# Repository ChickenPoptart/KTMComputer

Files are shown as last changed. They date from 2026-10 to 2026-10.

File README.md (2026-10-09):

# KTM Computer

A DIY dashboard and data logger for a **2020 KTM 690 Enduro R**, which has
no instrument cluster. An ESP32 "Cheap Yellow Display" reads the bike's
factory CAN bus (read-only) and a GPS module, shows a live dash on a 2.8"
touchscreen, keeps trip stats and charts, and logs everything to a MicroSD
card.

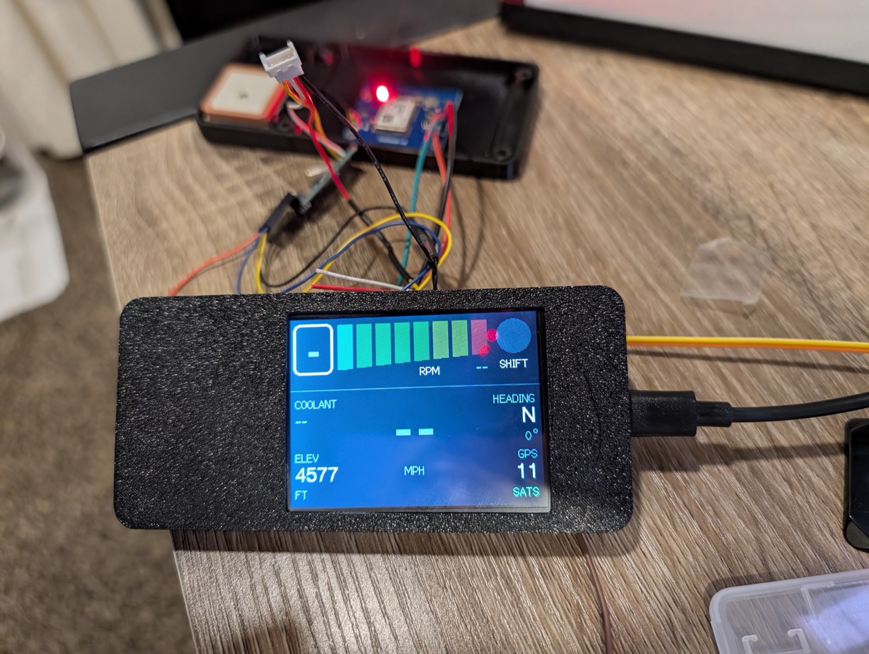
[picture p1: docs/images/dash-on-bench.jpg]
The dash on the bench: tach bar, gear, coolant, heading, elevation and GPS satellites, in a 3D-printed case with the GPS and wiring behind it


```mermaid
flowchart LR
    subgraph Bike
        ECU[ECU] --- BUS((CAN bus<br/>500 kbps))
        ABS[ABS unit] --- BUS
        BUS --- DIAG[6-pin diagnostic<br/>connector]
        DIAG --- DONGLE[Offroad ABS<br/>dongle]
        BAT[Battery]
    end
    DONGLE -- "CAN-H / CAN-L" --> XCVR[SN65HVD230<br/>CAN transceiver]
    DONGLE -- "switched 12 V" --> FUSE[1–2 A fuse] --> BUCK[12 V → 5 V<br/>converter]
    XCVR -- "CAN RX/TX (3.3 V)" --> CYD[ESP32-2432S028R<br/>'CYD' touchscreen]
    BUCK -- "5 V" --> CYD
    GPS[u-blox NEO-M8N<br/>GPS] -- "NMEA, 9600 baud" --> CYD
    CYD --> SD[(MicroSD<br/>ride logs)]
```

## What it does

- **Dashboard:** RPM with a colour-zoned tach bar and shift light, gear,
  speed (from the wheel sensor), coolant temperature, GPS heading,
  elevation, satellites, and the local time from GPS.
- **Trip and history pages:** distance, ride and moving time, maximums,
  climb and descent; charts of elevation, speed (wheel vs GPS) and coolant;
  time in each RPM zone. Every ride is saved, and `<` `>` buttons step
  through past rides.
- **CAN sniffer pages:** every CAN ID on the bus with its rate and live
  bytes, for reverse-engineering more signals.
- **Logging:** every CAN frame and GPS sentence to the SD card, one file per
  key-on, oldest deleted automatically when the card fills.
- **Read-only:** the CAN controller runs in listen-only mode. See the
  [wiring guide](docs/wiring.md#make-the-tap-truly-read-only) for the
  hardware change that guarantees it.

## Compatibility

| Bike | Years | Status |
|---|---|---|
| **KTM 690 Enduro R** | 2020 | **Built and tested** |
| KTM 690 Enduro R / SMC R | 2019+ | Same platform and electronics; should work |
| Husqvarna 701 Enduro / Supermoto | 2019+ era | Same platform and Bosch cornering ABS; should work, untested |
| GasGas ES 700 / SM 700 | 2022+ | Built on the same 690 platform; should work, untested |
| KTM 690 Enduro / SMC, older generation | pre-2019 | Different electronics (no IMU or cornering ABS); CAN signals probably differ, untested |

"Should work" means the hardware and logging will work and the
[CAN decoding](docs/can-signals.md) very likely matches; any differences
show up on the CAN sniffer pages and are a small code change.

**Diagnostic connector.** The tap is the 6-pin diagnostic connector under
the seat, near the battery's negative terminal:

- **2019–2020 (pre-Euro 5):** white connector (the tested bike).
- **2021+ (Euro 5):** most markets moved to a red connector with a
  different pin layout for the CAN wires. North American bikes may have kept
  the white one, so check the bike rather than going by year.

Either works: the [wiring guide](docs/wiring.md#finding-the-wires-with-a-meter)
finds the CAN pair, ground and switched 12 V with a meter, so wire colours
and pin positions don't need to match the tested bike.

**The offroad ABS dongle isn't required.** The tested bike splices into the
dongle's wires because one was fitted. Without one, splice into the bike
side of the diagnostic connector, or build a plug-in harness with the
mating 6-pin connector (Sumitomo MT 090 series) so nothing on the bike gets
cut.

## Screenshots

From a ride on the bike.

| | |
|---|---|
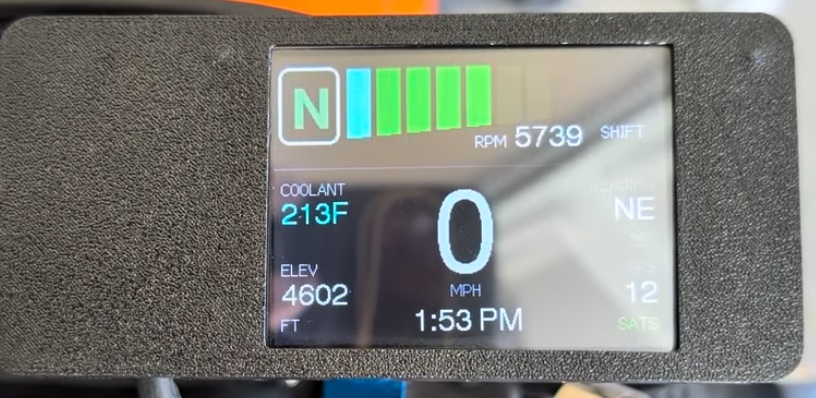
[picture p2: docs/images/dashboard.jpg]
Dashboard: neutral, 5,739 rpm on the green tach bar, coolant 213 °F, 0 mph, heading NE, elevation 4,602 ft, 12 satellites, 1:53 PM
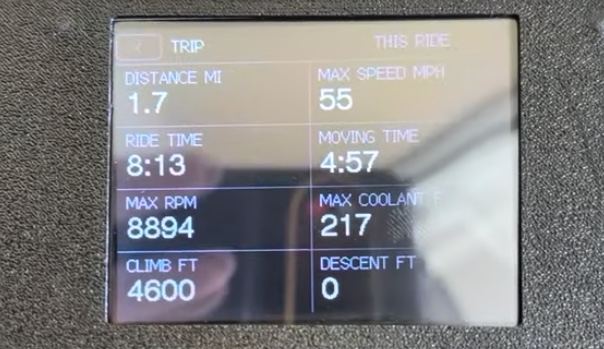
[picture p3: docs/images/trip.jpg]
Trip page: 1.7 mi, max 55 mph, ride time 8:13, moving time 4:57, max 8,894 rpm, max coolant 217 °F
|  |  |
| **Dashboard** | **Trip** |
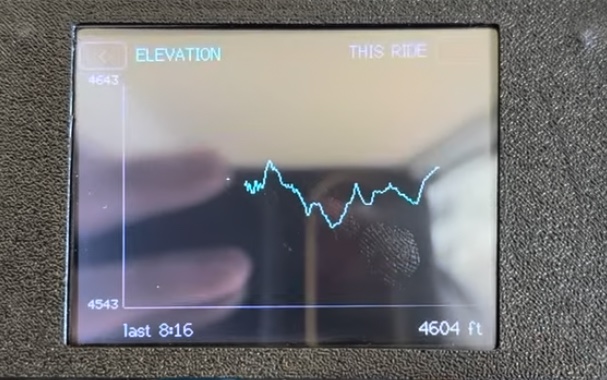
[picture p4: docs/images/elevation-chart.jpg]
Elevation chart over the ride, 4,543 to 4,643 ft
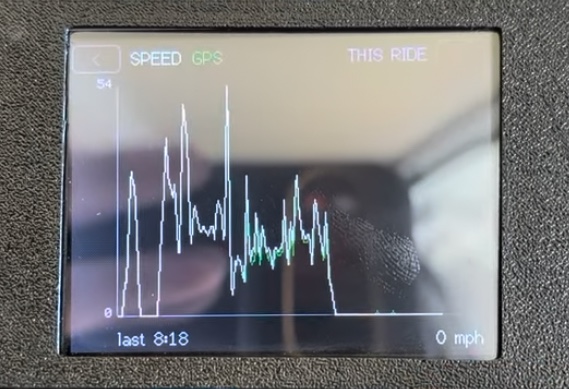
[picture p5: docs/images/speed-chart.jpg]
Speed chart: wheel speed with GPS speed overlaid, up to 54 mph
|  |  |
| **Elevation** | **Speed** (wheel, with GPS in green) |
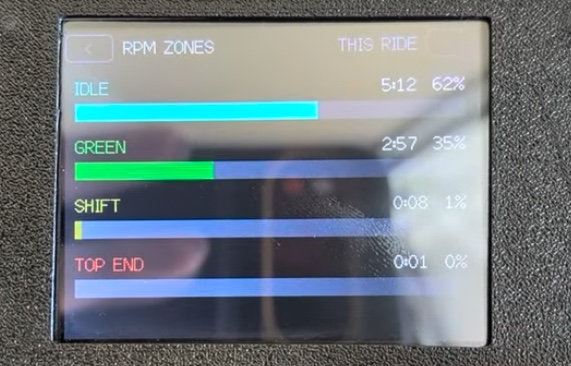
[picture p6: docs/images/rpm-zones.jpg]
RPM zones: idle 62%, green 35%, shift 1%, top end 0%
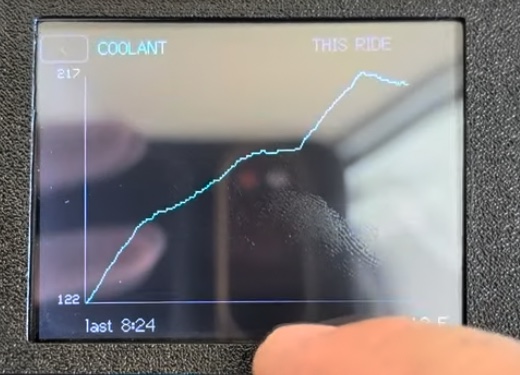
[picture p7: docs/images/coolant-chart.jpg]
Coolant chart warming from 122 °F to 217 °F
|  |  |
| **RPM zones** | **Coolant** |
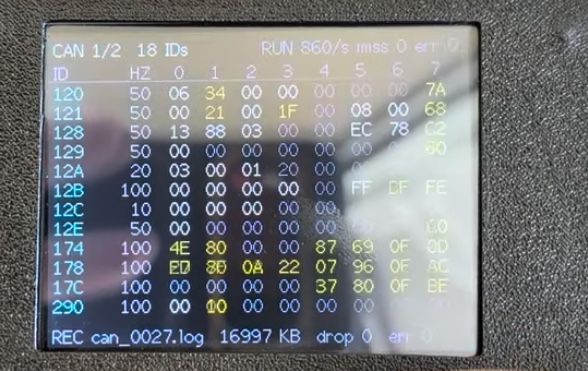
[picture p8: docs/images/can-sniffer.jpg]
CAN sniffer page: 18 IDs at 860 frames/s with live bytes, recording to can_0027.log, no drops
|  | |
| **CAN sniffer** | |

## Documentation

| Doc | What's in it |
|---|---|
| [Parts list](docs/parts-list.md) | Everything used in the build |
| [Wiring](docs/wiring.md) | Every wire: bike, power, transceiver, GPS, with pin tables |
| [Build guide](docs/build-guide.md) | Step by step: tools, flashing, wiring, testing on the bike |
| [Using the dash](docs/using-the-dash.md) | Pages, taps, long presses, ride history |
| [CAN signals](docs/can-signals.md) | What each CAN ID and byte means on this bike |
| [Log format](docs/log-format.md) | What's in the SD card logs and how to read them |
| [Firmware](docs/firmware.md) | Code layout, tests, settings you might change |
| [Troubleshooting](docs/troubleshooting.md) | Problems hit during the build and how they were found |
| [Roadmap](docs/roadmap.md) | What's done and what's next |
| [Case](hardware/case/README.md) | 3D-printable case (STL) |
| [Captures](captures/README.md) | Raw CAN logs from the bike |

## Quick start (firmware)

1. Install [VS Code](https://code.visualstudio.com/) and the
   [PlatformIO](https://platformio.org/install/ide?install=vscode) extension.
2. Clone this repo and open the folder in VS Code.
3. Plug the CYD into the computer by USB and press **Upload** in the
   PlatformIO toolbar (or run `pio run -e esp32dev -t upload`).
4. Run the unit tests on the computer with `pio test -e native`.

See the [build guide](docs/build-guide.md) for the hardware.

## Credits

The starting point for the CAN decoding is
[blalor/ktm-can](https://github.com/blalor/ktm-can), also from a 2020 690
Enduro R, built on Dan Plastina's SuperDuke 1290 work on ADVrider. This
project confirmed and extended it from its own ride logs.

## License

**Free for personal and other noncommercial use.**

- **Code** (`src/`, `lib/`, `test/`, `platformio.ini`):
  [PolyForm Noncommercial 1.0.0](LICENSE)
- **Docs, images, 3D files and captures:**
  [CC BY-NC-SA 4.0](LICENSE-docs.md): credit this project and share
  adapted versions under the same terms

Build one for your own bike, modify it, share it with friends and
clubs: all fine.

### Commercial use

Selling kits or finished units, including this in a product, or charging to
install it needs a commercial license. To ask, open an issue using the
[**Commercial license request**](https://github.com/ChickenPoptart/KTMComputer/issues/new?template=commercial-license.md)
template.

### Earlier versions

Versions published before 9 October 2026 (up to commit `f2c9ddf`) were
released under the MIT License, and anyone who got a copy of those versions
keeps the MIT terms for them.

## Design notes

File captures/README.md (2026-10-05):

# CAN captures

Raw logs from the bike, in the [log format](../docs/log-format.md)
(candump lines, plus `mark` lines for markers). All are from firmware that
lost 25–50% of frames ([why](../docs/troubleshooting.md#lost-can-frames-fixed)),
so rolling counters skip; slower signals are still usable.

GPS lines are removed from anything published here, since they show where
the bike was.

| File | Length | What happened |
|---|---|---|
| `2026-09-28_first_start_can_0005.log` | 40 s | First key-on: ECU wakes at ~16 s, cold start at ~25 s, idle ~1,700 rpm, engine off at 39 s |
| `2026-10-01_can_0007.log` | 35 s | Key-on |
| `2026-10-01_can_0008.log` | 89 s | Key-on with 5 markers (first attempt at the test plan) |
| `2026-10-01_can_0009.log` | 14 s | Key-on |
| `2026-10-01_can_0010.log` | 6.5 min | **Full test ride with 13 markers** (below) |

## Markers in `2026-10-01_can_0010.log`

| Mark | Action | Found |
|---|---|---|
| 1 | Front brake, squeezed 3× | `290` D0–D1 |
| 2 | Rear brake, 3× | nothing distinctive |
| 3 | Clutch in/out 3× | `129` D0 bit 3 |
| 4 | Kickstand up, then down | `540` D4 bit 0 |
| 5 | TC button | `450` D2 bit 0 |
| 6 | Throttle map changed and back | `12A` D1 bit 6, `120` D4 bit 0, `450` D4 |
| 7 | Leaning left / right | `178`, `17C` swing |
| 8 | Throttle sweeps (engine started in this window) | `120` D2, `121` D1/D3 |
| 9 | Roll-on to ~5,000 rpm | |
| 10 | Throttle blips | |
| 11 | Steady ~20–25 mph (1st gear) | `12B` wheel speeds ~615 raw |
| 12 | Steady ~38–42 mph (2nd gear) | `12B` ~1,113 raw |
| 13 | Normal riding | |

## Reading them

```sh
# CAN frames only
grep ' can0 ' 2026-10-01_can_0010.log

# One ID
grep ' can0 120#' 2026-10-01_can_0010.log
```

Tools that read candump logs (python-can, SavvyCAN, cantools) can open the
files once the `mark` lines are filtered out.

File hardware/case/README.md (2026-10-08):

# Case for the 2.8" CYD dash

`cyd-case.stl` is the 3D-printed case for the current build (ESP32-2432S028R
"Cheap Yellow Display"). All parts are laid out on one plate, 207 × 167 mm,
so it prints in one go on a 220 mm bed or larger.

| Part | Size (mm) | What it is |
|---|---|---|
| Dash front | 119 × 55 × 13 | Holds the CYD, with the screen opening |
| Dash back | 119 × 55 × 8 | Back cover |
| Electronics box | 58 × 123 × 17 | Houses the GPS and wiring |
| Posts (×4) | 6.5 × 6.5 × 20 | Standoffs |

The file also contains two zero-thickness slivers left over from export;
slicers ignore them.

## Printing

- **PETG or ASA**, not PLA: a black case on handlebars gets hot enough in
  the sun to warp PLA.
- The GPS antenna works through the plastic (1.5 mm PETG tested fine), so
  keep the GPS box's lid plastic, with no metal above the antenna.
- Leave the SD card slot and USB-C reachable for pulling logs and flashing.

See the [build guide](../../docs/build-guide.md#8-mounting) for mounting.

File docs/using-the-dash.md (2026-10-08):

# Using the dash

## Touch

| Gesture | Does |
|---|---|
| **Tap** | Next page (shows ~⅓ s after lifting, to tell it from a double tap) |
| **Double tap** | Back to the dashboard, from any page, and back to this ride |
| **Hold ~1 s** on the dashboard or CAN pages | Drops a numbered **marker** into the log (yellow `MARK n` box) |
| **Hold ~1 s** on a trip or chart page | Shows **TAP TO CLEAR**: tap within 3 s to clear that page's data for this ride, or wait to cancel |
| **`<` / `>`** (top corners of the trip and chart pages) | Step to older / newer saved rides |

## Pages

Tap to cycle in this order:

1. **Dashboard:** tach bar, RPM, shift light, gear, speed, coolant, GPS
   heading, elevation, satellites, time.

   Dashboard

2. **Trip:** distance, max speed, ride time, moving time, max RPM, max
   coolant, climb, descent.

   Trip page

3. **Elevation** chart (GPS).

   Elevation chart

4. **Speed** chart: wheel speed (white) with GPS speed (green).

   Speed chart

5. **RPM zones:** time and share in idle, green, shift and top end.

   RPM zones

6. **Coolant** chart.

   Coolant chart

7. **CAN pages:** every CAN ID with its rate and bytes (yellow = changed
   in the last second, white = has changed, grey = never changed), plus bus
   state and SD recording status.

   CAN sniffer page

## Dashboard

| Item | Source | Notes |
|---|---|---|
| Tach bar | RPM (`0x120`) | Cyan from 1,000 (idle), green 3,000–5,700, yellow 6,500–7,300, red at 8,200, where the bar flashes and the shift light comes on. Thresholds are `TACH_SEGMENT_RPM` in `lib/dash_logic/src/dash_logic.h` |
| Gear | `0x129` | `N` in green; `-` with no data |
| MPH | Front wheel speed (`0x12B`) | Instant (100 updates/s). Scale ~27.4 counts per mph, about ±5% until calibrated against GPS |
| Coolant | `0x540` | °F |
| Heading | GPS course | Only updates above 3 mph; holds the last heading when stopped |
| Elevation | GPS altitude | ±30–60 ft typical |
| GPS / SATS | GPS | `NO FIX` until it has a position |
| Time | GPS | Mountain time with daylight saving. `--:--` until the GPS sets the clock. Shows **CAN FAULT** in red instead if the CAN wiring looks broken |

Anything that stops arriving for more than a second turns to `--`.

## Trip, charts and ride history

- Everything is collected all the time, whatever page is showing, starting
  fresh at each key-on.
- Charts take a point every 2 seconds. Each holds 280 points; when full,
  neighbouring points are averaged in pairs, so the chart always shows the
  **whole ride**, at less detail the longer it gets. Maximums on the Trip
  page are tracked separately at full speed, so short spikes are never lost.
- Climb/descent ignores GPS jitter smaller than 30 ft.
- **A ride** is one key-on with at least a minute of engine running. It's
  saved to the SD card every 30 seconds (`/rides/ride_NNNN.bin`), so turning
  the key off loses at most 30 s. Bench power-ups aren't saved.
- On a past ride the header shows its number and date, e.g.
  `#17 Sat Oct 4`. Past rides can't be cleared.

## Markers

Hold on the dashboard to mark a moment ("I squeezed the front brake now").
Markers go into the log as `mark` lines, so the bytes that changed at that
moment are easy to find later. The count restarts at 1 each key-on.

## The SD card

- One `can_NNNN.log` per key-on, plus `/rides/` for ride history.
- Copy logs you want to keep. When the card is under 10% free at boot, the
  oldest logs (and their ride history) are deleted.
- After the GPS has a fix, files get real dates on the computer.

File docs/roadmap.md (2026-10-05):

# Roadmap

## Done

- Read-only CAN sniffer with SD logging (every frame, candump format)
- Live dashboard: RPM and colour-zoned tach, shift light, gear, wheel
  speed, coolant
- CAN signal decoding for RPM, gear, coolant, wheel speed, brake, clutch,
  kickstand, TC and map buttons ([CAN signals](can-signals.md))
- Event markers (hold on the dashboard)
- GPS (NEO-M8N): fix, satellites, heading, elevation, local time with
  daylight saving; every sentence logged
- Trip page, elevation / speed / coolant charts, RPM zone breakdown
- Ride history: every ride saved, `<` `>` to browse; double tap to the
  dashboard
- Automatic log rotation when the card fills
- CAN error guard and loop profiling notes
- Running on the bike from VIN power, with the bus short repaired (2026-10-05)

## Next

- **Calibrate wheel speed against GPS speed** from a ride log, replacing
  the ±5% estimate
- **Read-only hardware change:** tie the transceiver's CTX to 3.3 V
  ([why](wiring.md#make-the-tap-truly-read-only))
- **GPX export** script for the computer: ride tracks coloured by speed or RPM
- More signals: rear brake, `300` (check with the dongle unplugged),
  lean angle, and the unknown IDs
- 3D-printed case and handlebar mount

## Maybe later

- GPS at 10 Hz (needs the GPS RX wire, from a freed RGB LED pin)
- BMP280 barometer for smoother elevation
- Magnetometer for heading at a standstill
- Live displays for the newly found signals (map, TC, kickstand warning)

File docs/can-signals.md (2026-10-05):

# CAN signals — 2020 KTM 690 Enduro R

What each CAN message on this bike carries, as far as it's been worked out.
The bus runs at **500 kbps** with standard 11-bit IDs. Bytes are D0..D7;
multi-byte values are big-endian (high byte first).

## What the dash uses

| Shown as | ID | Bytes | Conversion |
|---|---|---|---|
| RPM | `0x120` | D0–D1 | value = RPM |
| Gear | `0x129` | D0 high nibble | 0 = neutral, 1–6 |
| Coolant | `0x540` | D6–D7 | value ÷ 10 = °C (dash shows °F) |
| Speed | `0x12B` | D0–D1 (front wheel) | value ÷ 27.4 = mph |

Decoding lives in `lib/dash_logic/src/ktm_decode.cpp`, with tests in
`test/test_ktm_decode`. A value that stops arriving for over a second shows
as `--`.

## All IDs seen
"Source" is which module starts sending first after key-on: the ECU starts
3–70 s after key-on, the others immediately (most likely the ABS unit).

Starting point: [blalor/ktm-can](https://github.com/blalor/ktm-can) (also a
2020 690 Enduro R). Marked **confirmed** where our own logs show it; ride
evidence is [`captures/2026-10-01_can_0010.log`](../captures/README.md) (13 markers, see below).

| ID | Period | Source | Contents | Status |
|---|---|---|---|---|
| `120` | 20 ms | ECU | D0–D1 engine rpm. D2 commanded throttle 0–255. D3 bit 4 kill switch (1 = run). D4 bit 0 throttle map in use. D7 high bits rolling counter | rpm, map **confirmed**; on dash |
| `121` | 20 ms | ECU | D1 and D3 rise together with the throttle grip (likely the two redundant ride-by-wire grip sensors). D7 rolling counter | candidate |
| `128` | 20 ms | key-on | `7FFF…` until the ECU wakes, then fixed values. D2 toggles 02/03 with the engine running | unknown |
| `129` | 20 ms | ECU | D0 high nibble gear (0 = N, 1–6); D0 bit 3 clutch pulled. D7 rolling counter | gear, clutch **confirmed**; gear on dash |
| `12A` | 50 ms | key-on | D1 bit 6 requested throttle map. D0 throttle open/closed bits | map **confirmed** |
| `12B` | 10 ms | key-on | D0–D1 front wheel speed, D2–D3 rear wheel speed (front and rear agree within ~3%). D5–D7 tilt/lean (12-bit pairs) | speed **confirmed**; front wheel on dash (~27.4 counts/mph); lean unverified |
| `12C` | 1 s | key-on | All zero when stopped; two 12-bit values that follow wheel speed (slower, different scale) | candidate |
| `12E` | ~100 ms | key-on | D0 status flag (00/40). D7 counter | unknown |
| `174` `178` `17C` | 10 ms | key-on | Lean/motion sensor: each has two 16-bit values centred near 0x8000 (one offset by gravity), a 4-bit counter in D6 low nibble, and a checksum in D7. `178` D0–D1 and `17C` D4–D5 swing most when leaning the bike | strong candidate |
| `290` | 10 ms | key-on | D0–D1 front brake pressure (rises only with the front lever) | **confirmed** |
| `300` | 200 ms | key-on | Always `0F…` | possibly the offroad ABS dongle; check with it unplugged |
| `450` | 50 ms | key-on | D2 bit 0 traction control button. D4 `09`/`00` with the map button | TC, map **confirmed** |
| `540` | 100 ms | ECU | D1–D2 rpm (slower copy). D3 low nibble gear. D4 bit 0 kickstand up; bit 4 key on, engine not running. D6–D7 coolant, tenths of °C | kickstand, coolant **confirmed**; coolant on dash |
| `541` | 200 ms | ECU | Always `02 80` | ECU status, unknown |
| `550` | 200 ms | key-on | D0 status flag (00/10). D7 counter | unknown |
| `5A0` | 1 s | key-on | D1/D2 change once after the ECU wakes | unknown |

Not found yet: **rear brake** (the pedal changed nothing distinctive).

## Wheel speed scale (`12B`)

Steady stretches from the 2026-10-01 ride, read against the bike's
speedometer:

| Speedometer | Steady stretch | Rear raw | Front raw | Gear |
|---|---|---|---|---|
| 20–25 mph | 219–232 s | ~615 | ~602 | 1 |
| 38–42 mph | 265–270 s | ~1,113 | ~1,095 | 2 |

The only scale that fits both runs is 26.5–29.3 rear counts per mph; the
midpoint ≈ 28 gives 22 and 40 mph. The front wheel reads ~2% lower, so the
dash uses 27.4 front counts per mph (`FRONT_COUNTS_PER_10_MPH` in
`lib/dash_logic/src/ktm_decode.cpp`). Expect about ±5%; a GPS track would
pin it down. The raw value is not a round km/h unit (0.05 and 0.0625 km/h
per count both fall outside the speedometer ranges). Logs now include GPS
speed, which will give an exact calibration.

## Ride markers (`captures/2026-10-01_can_0010.log`)

1 front brake · 2 rear brake · 3 clutch · 4 kickstand · 5 TC button ·
6 throttle map · 7 lean left/right · 8 throttle sweep · 9 roll-on to 5,000 ·
10 blips · 11 steady 20 mph · 12 steady 40 mph · 13 normal ride

## Log quality

Firmware before 2026-10-01 echoed changed frames to Serial, which blocked
the loop about every 10 ms and lost 25–50% of frames (visible as skipped
rolling counters in `120`, `129`, `174`). Slow signals are still usable.

## Reading the bytes yourself

- A frame in the log looks like `(12.345678) can0 120#06A4101000000030`:
  ID `120`, data `06 A4 10 10 00 00 00 30`. D0–D1 = `06A4` = 1700 rpm.
- **Rolling counters** (a byte or nibble stepping by a fixed amount every
  frame) show up in many IDs. A skipped step means a frame was lost, which
  is how frame loss in early logs was measured.
- To find a new signal: hold the screen on the dashboard to drop a marker,
  do the action, and compare which bytes change after the marker but not
  in quiet stretches. That's how the brake, clutch, kickstand, TC and map
  bits above were found.

## Still to find

- Rear brake (the pedal changed nothing distinctive)
- What `300` is: log one key-on with the offroad dongle unplugged
- `121`, `128`, `12C`, `12E`, `541`, `550`, `5A0`: unknown or only partly known
- Lean angle scaling (`12B` D5–D7, and the motion sensor IDs)

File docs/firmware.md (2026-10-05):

# Firmware

PlatformIO project, Arduino framework on the ESP32. Two environments:

| Environment | Command | What |
|---|---|---|
| `esp32dev` | `pio run -e esp32dev -t upload` | Builds and flashes the CYD |
| `native` | `pio test -e native` | Runs the unit tests on the computer |

## Layout

Logic that doesn't touch hardware lives in `lib/dash_logic/` and has unit
tests in `test/`. Code that talks to the display, CAN controller, GPS, touch
panel or SD card lives in `src/`.

### `lib/dash_logic/src/` (tested on the computer)

| File | Does |
|---|---|
| `ktm_decode` | Turns CAN frames into RPM, gear, coolant, speed, with staleness |
| `can_tracker` | Per-ID table for the CAN pages (rates, changed bytes) |
| `can_guard.h` | Decides when a CAN error flood means CAN should pause |
| `candump_format` | Log line formats: CAN frames, markers, GPS sentences |
| `dash_logic` | Tach segments and colour zones, gear labels, compass points, durations |
| `gps_view.h` | GPS fix, heading hold below 3 mph, elevation |
| `ride_clock` | GPS date/time to epoch, Mountain time with daylight saving |
| `trip_stats.h` | Distance, times, maximums, climb/descent, time per RPM zone |
| `chart_series.h` | Chart storage that merges pairs so a whole ride fits |
| `ride_history.h` | Ride file names, which rides to save, `<` `>` browsing |
| `log_rotation` | Log file numbering and deleting the oldest when the card fills |
| `press_detector.h`, `tap_sequencer.h` | Tap / long press / double tap from the touch panel |
| `reset_prompt.h` | The two-step "TAP TO CLEAR" |
| `touch_map.h` | Touch calibration: raw panel readings to screen pixels |
| `loop_profiler.h` | Where the main loop's time goes (diagnostic notes) |

### `src/` (hardware)

| File | Does |
|---|---|
| `main.cpp` | Setup, the main loop, pages, touch handling, ride saving |
| `can_bus` | ESP32 TWAI controller, listen-only, 500 kbps, plus the error guard |
| `gps` | NEO-M8N on UART2 (IO35), TinyGPSPlus parser, logs every sentence |
| `sd_log` | SD card, background writer task on core 0, log rotation, notes |
| `ride_store` | Saves and loads `/rides/ride_NNNN.bin` |
| `touch` | Bit-banged XPT2046 touch controller |
| `dash_ui`, `trip_page`, `chart_page`, `zones_page`, `can_page`, `history_header` | Screens |
| `telemetry.h` | What the dashboard shows |

## Settings you might change

| Setting | File | Default |
|---|---|---|
| Tach colour zones | `TACH_SEGMENT_RPM` in `dash_logic.h` | 1000 / 3000 / 3900 / 4800 / 5700 / 6500 / 7300 / 8200 |
| Shift light | `SHIFT_RPM` in `dash_logic.h` | 8,200 |
| Speed scale | `FRONT_COUNTS_PER_10_MPH` in `ktm_decode.cpp` | 274 (27.4 counts per mph) |
| Time zone | `MOUNTAIN_TZ` in `ride_clock.h` | US Mountain with DST |
| Screen rotation | `SCREEN_ROTATION` in `main.cpp` | 1 (redo touch calibration if changed) |
| Free space kept on the card | `MIN_FREE_PERCENT` in `log_rotation.h` | 10% |
| Minimum engine time for a saved ride | `RIDE_MIN_SECONDS` in `ride_history.h` | 60 s |
| Double-tap window | `DOUBLE_TAP_MS` in `tap_sequencer.h` | 350 ms |

Changing anything in `RideRecord` (`src/ride_store.h`) or what it contains
changes the saved-ride file layout: bump `RIDE_VERSION` in
`ride_store.cpp` so older files are skipped instead of misread.

## How the main loop runs

Each pass: drain up to 64 CAN frames, read the GPS, update trip stats
(every 100 ms) and charts (every 2 s), save the ride (every 30 s), handle
touch, then redraw the current page at its own rate (dashboard every
40 ms). Nothing in the loop waits on hardware: SD writes go through a queue
to a task on the other core, and serial carries only occasional status
lines.

## Serial output (USB, 115200 baud)

Status only: boot messages, a GPS line every 5 seconds
(`# GPS chars=… sats=… fix=… time=…`), and the same `note` lines that go
into the log.

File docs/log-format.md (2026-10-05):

# SD card ride logs

One file per power-up: `can_NNNN.log`. Numbers only go up (one past the
highest on the card), so the lowest number is the oldest log.

Every line starts with a timestamp in seconds since boot, then a channel:

| Channel | Example | What |
|---|---|---|
| `can0` | `(12.345678) can0 120#05DC101000000030` | Every CAN frame from the bike, candump format |
| `mark` | `(31.676005) mark 000#0001` | Long-press marker number (hex), restarts at 1 each boot |
| `nmea` | `(3.250000) nmea $GNRMC,…*47` | Every sentence from the NEO-M8N GPS, unchanged |
| `note` | `(10.000172) note loop passes=576448 slowest=21ms …` | Diagnostics in plain text (see below) |

`can0` and `mark` lines are valid candump syntax; tools that read candump
logs may need the `nmea` and `note` lines filtered out first
(`grep -v -e ' nmea ' -e ' note ' can_0012.log`). GPS tools that read NMEA can take the
sentences with `grep ' nmea ' can_0012.log | cut -d' ' -f3-`.

## Notes

| Note | When | Says |
|---|---|---|
| `boot reset_reason=… can=… sd=…` | At startup | Why the board last reset (1 = power-on), whether CAN and the SD card started |
| `loop passes=… slowest=…ms can=…ms gps=…ms …` | Every 10 s | How many main-loop passes ran and where the time went; ~600,000 passes per 10 s is normal. Also SD bytes written and lines dropped |
| `can frames=… errors=…` | Every 10 s | Running totals from the CAN controller; `FAULT` while an error flood is being handled |
| `CAN error flood …: CAN off for 10 s` / `CAN restarted` | On a fault | The [CAN error guard](troubleshooting.md#can-fault-on-the-dash) acting |

## Ride history files

`/rides/ride_NNNN.bin` holds the trip stats and charts for the ride logged
in `can_NNNN.log`, saved every 30 seconds. It's a raw memory image with a
small header (magic `KTMR`, version, size); files from a different firmware
version are skipped rather than misread.

## Space on the card

At boot, before recording starts, the firmware deletes the oldest logs
until at least 10% of the card is free (`MIN_FREE_PERCENT` in
`lib/dash_logic/src/log_rotation.h`). A log is roughly 50–80 MB per hour of
riding, so 10% of a 32 GB card is ~40 hours: one ride can't fill it, and
nothing is deleted mid-ride. Copy logs you want to keep off the card; old
ones disappear once it fills.

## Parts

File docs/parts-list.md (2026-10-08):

# Parts list

What this build uses. Exact brands mostly don't matter; the notes say what
does.

## Electronics

| Part | Qty | Notes |
|---|---|---|
| **ESP32-2432S028R** ("Cheap Yellow Display", CYD) | 1 | ESP32 with a 2.8" 320×240 ILI9341 screen, resistive touch, MicroSD slot. The firmware's pins and touch calibration are for this board |
| **SN65HVD230 CAN transceiver board** | 1 | 3.3 V CAN transceiver, chip marked "VP230". Leave its 120 Ω termination jumper **off** (the bike's bus is already terminated) |
| **u-blox NEO-M8N GPS breakout** with ceramic patch antenna | 1 | Breakout marked NEO-M8N-0-10. Pins: VCC, GND, TX, RX. Runs from the CYD's 3.3 V. No compass on this one |
| **12 V → 5 V converter** with USB-A output | 1 | Any automotive buck converter rated 1 A or more at 5 V. Use USB-A, not a USB-C PD charger |
| **Inline fuse holder + 1–2 A fuse** | 1 | On the converter's 12 V input |
| **MicroSD card**, FAT32 | 1 | 32 GB or smaller (larger cards ship as exFAT, which the board can't read). Holds hundreds of hours of logs |

## Wire and connectors

| Part | Notes |
|---|---|
| **Cat5e or Cat6 cable** | For the run from the bike tap to the transceiver. CAN-H and CAN-L go on **one twisted pair**; a spare conductor carries ground |
| **USB-A cable** (sacrificial) | Cut to make the 5 V lead from the converter to the CYD's VIN. Inside: +5 V (gray in the one used), ground (bare drain wire/shield), data wires unused |
| **JST 1.25 mm 4-pin pigtails** (also sold as MX1.25 / Molex PicoBlade-compatible) | Fit the CYD's CN1, P3 and power connectors. One cable usually comes with the CYD. Not the same as 2.0 mm JST-PH |
| **Heat-shrink tubing**, assorted | One piece per joint. See the [warning in troubleshooting](troubleshooting.md#a-melted-wire-shorted-the-bus) about heat |
| **Solder**, flux, thin hookup wire (28–30 AWG for fine joints) | |
| Zip ties | Strain relief at every joint |
| Quick disconnect (optional) | Any cheap latching connector between the bike pigtail and the dash, e.g. JST-SM 4-pin. Put the socket half on the bike side |

## Already on the bike

| Part | Notes |
|---|---|
| **Offroad ABS dongle** | Plugs into the 6-pin diagnostic connector under the seat. The dash taps the dongle's wires, so the dongle must stay plugged in |

## Tools

| Tool | Used for |
|---|---|
| Multimeter (a basic manual-range one is fine) | Finding the CAN pair, checking power, finding shorts |
| Soldering iron | All joints |
| Heat gun or lighter | Heat-shrink, carefully |
| Computer with VS Code + PlatformIO | Building and flashing the firmware |
| USB cable for the CYD | Flashing and serial monitor |

## Planned / optional

| Part | Why |
|---|---|
| 3D-printed case (PETG or ASA, not PLA): [`hardware/case`](../hardware/case/README.md) | PLA warps in the sun. The GPS works through 1.5 mm of PETG |
| Handlebar mount (e.g. RAM 1" ball with an AMPS plate) | Quick removal when it rains |
| BMP280 barometer | Smoother elevation than GPS alone |
| Magnetometer | Compass heading while stopped (hard to calibrate near the frame) |

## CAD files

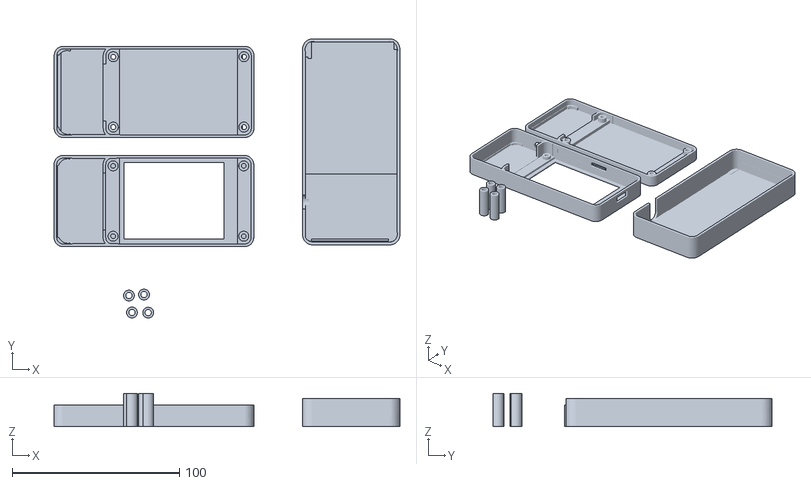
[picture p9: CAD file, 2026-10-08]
hardware/case/cyd-case.stl
206.6 x 166.7 x 20.0

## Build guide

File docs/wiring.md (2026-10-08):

# Wiring

Every wire in the build. Wire colours on the bike side are from this
bike's offroad ABS dongle (2020, white pre-Euro 5 diagnostic connector);
**confirm yours with a meter** before cutting anything (see
[Finding the wires](#finding-the-wires-with-a-meter)). Other model years
and connectors are covered under [Compatibility](../README.md#compatibility).

```mermaid
flowchart LR
    subgraph Dongle["Offroad ABS dongle wires (bike side)"]
        TAN[Tan<br/>switched 12 V]
        BRN[Brown<br/>ground]
        BB[Blue/black<br/>CAN-H]
        BW[Blue/white<br/>CAN-L]
    end
    TAN --> FUSE[1–2 A fuse] --> CIN[Converter 12 V +]
    BRN --> CGND[Converter 12 V −]
    BRN --> XGND[Transceiver GND]
    BB --> XH[Transceiver CANH]
    BW --> XL[Transceiver CANL]
    CIN -.-> CONV[12 V → 5 V converter]
    CONV -- "gray: +5 V" --> VIN[CYD VIN]
    CONV -- "drain wire: GND" --> CYDGND[CYD GND]
    subgraph CN1["CYD CN1"]
        R[Red 3V3]
        Y[Yellow IO27]
        BL[Blue IO22]
        BK[Black GND]
    end
    R --> X3[Transceiver 3V3]
    Y --> XR[Transceiver CRX]
    BL --> XT[Transceiver CTX]
    BK --> XGND
    R --> GV[GPS VCC]
    GT[GPS TX] --> P35[CYD P3 IO35]
    GG[GPS GND] --> P3G[CYD P3 GND]
```

## 1. Bike: the offroad ABS dongle

The dongle plugs into the bike's 6-pin diagnostic connector under the seat
(below the ECU). The dash splices into the **dongle's** wires, so the
dongle has to stay plugged in.

| Dongle wire | Signal | Goes to |
|---|---|---|
| **Tan** | Switched 12 V (live only with the key on) | Inline **1–2 A fuse**, then converter 12 V **+** |
| **Brown** | Ground | Converter 12 V **−**, and transceiver **GND** |
| **Blue/black** | **CAN-H** | Transceiver **CANH** |
| **Blue/white** | **CAN-L** | Transceiver **CANL** |

- Run CAN-H and CAN-L on **one twisted pair** of Cat5e/6, untwisted as little
  as possible at the ends. Use a spare conductor for ground.
- Keep the branch from the dongle to the transceiver short (a foot or two).
- Take both grounds (converter − and transceiver GND) from the **same**
  brown-wire splice point.
- **Tan never connects to the CYD, transceiver or GPS.** 12 V destroys them.

## 2. Power

```
Tan (12 V, switched) ──fuse──► converter ──5 V──► CYD VIN ──► CYD 3.3 V regulator ──► CN1 red (3V3)
                                                                                          ├──► transceiver 3V3
                                                                                          └──► GPS VCC
```

Power enters only at **VIN**. The CYD makes 3.3 V and supplies it on CN1's
red wire; the transceiver and the GPS run from that.

**Converter to CYD** (a cut USB-A cable, plugged into the converter):

| Cable wire | CYD power connector (labelled VIN / TX / RX / GND) |
|---|---|
| **Gray** (+5 V in the cable used; check yours) | **VIN** |
| **Bare drain wire** (+ shield) | **GND** |
| Green, white (data) | Not connected; insulate each |
| — | **TX, RX: not connected** (they're the USB serial lines) |

Find +5 V in your cable with the meter on DC volts: with the converter
powered, the pair that reads **+5.0 V** (red probe on +) is power.

- Never put 5 V on 3V3, the transceiver or the GPS.
- **Don't connect USB and VIN at the same time.** Unplug the bike side
  before plugging the CYD into a computer to flash it.

## 3. CYD CN1 → CAN transceiver

| CN1 pin | Wire | ESP32 | Transceiver |
|---|---|---|---|
| 1 | Red | 3V3 | **3V3** |
| 2 | Yellow | IO27 (CAN RX) | **CRX** |
| 3 | Blue | IO22 (CAN TX) | **CTX** (see below) |
| 4 | Black | GND | **GND** |

Termination: the bike's bus already has both 120 Ω terminators (measured
**60.2 Ω** across CAN-H/CAN-L, key off, dongle plugged in). Leave the
transceiver's 120 Ω jumper **off**.

### Make the tap truly read-only

The firmware runs the CAN controller in listen-only mode: it never sends
frames or acknowledgements. But on the ESP32, a listen-only controller can
still drive **error flags** onto the bus when it sees errors (chip errata;
the workaround isn't enabled in this framework build). To make it
physically impossible for the dash to transmit:

- Disconnect the blue IO22 wire from the transceiver's **CTX**.
- Connect **CTX to 3.3 V** (the red 3V3 line).

The transceiver then holds the bus "recessive" (silent) whatever the ESP32
does. No firmware change is needed.

## 4. GPS (u-blox NEO-M8N)

| GPS pin | CYD |
|---|---|
| **VCC** | 3.3 V: splice into CN1's **red** wire |
| **GND** | **P3 GND**, or CN1's black wire |
| **TX** | **P3 IO35** (UART2 receive; IO35 is input-only, which is all it needs) |
| **RX** | Not connected; insulate it |

- P3 also carries **IO22** (the same CAN TX line as CN1) and on many boards
  **IO21** (screen backlight). Use only IO35 and GND on P3.
- Power the GPS from 3.3 V. Breakouts that accept 3.3–5 V run fine on it;
  3.3 V-only ones would be destroyed by 5 V.
- The ceramic patch faces the sky, nothing metal above it. Plastic (e.g.
  1.5 mm PETG) is fine. Keep it a few inches from the screen if possible.
- Wiring GPS RX later (from a freed RGB LED pin: GPIO 4, 16 or 17) would let
  the firmware switch the GPS to 10 Hz.

## 5. Pins used on the ESP32

| GPIO | Use |
|---|---|
| 2, 12, 13, 14, 15, 21 | Display (HSPI; 21 = backlight) |
| 5, 18, 19, 23 | MicroSD (VSPI) |
| 25, 32, 33, 36, 39 | Touch controller (bit-banged; 36 = pen IRQ) |
| 27 | CAN RX (from transceiver CRX) |
| 22 | CAN TX (to transceiver CTX, or unused after the read-only change) |
| 35 | GPS RX (from GPS TX) |
| 1 | Serial TX (USB status messages) |
| 3 | Serial RX: **disconnected in firmware**, see [troubleshooting](troubleshooting.md#the-dash-froze-on-vin-power) |

## Finding the wires with a meter

How the dongle's wires were identified. Key **off** for resistance tests.

| Test | Meter | Expect | Means |
|---|---|---|---|
| Wire pairs, key off | Ω 200 | **~60 Ω** | The CAN pair |
| Each wire to battery −, key off | Ω 200 | **~0 Ω** | Ground |
| CAN pair to battery −, key on | DC V 20 | **2.5–3.5 V** / **1.5–2.5 V** | CAN-H / CAN-L |
| Others to battery −, key on | DC V 20 | **~12 V** | Power; check it reads **0 V with the key off** to confirm it's switched |

## Checks before connecting to the bike

With the dash wiring disconnected from the bike (dongle unplugged), meter on Ω 200:

| Measure | Expect |
|---|---|
| CAN-H to GND | high / open |
| CAN-L to GND | high / open |
| CAN-H to CAN-L | high / open |
| 12 V (tan) to GND | high / open |

Then with the dongle plugged into the bike: **CAN-H to CAN-L ≈ 60 Ω** (key
off), and with the key on **both lines around 2.5 V**. If both read near
0 V, something is shorting the bus to ground (see
[troubleshooting](troubleshooting.md#a-melted-wire-shorted-the-bus)).

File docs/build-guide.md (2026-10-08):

# Build guide

From parts on the bench to a working dash on the bike. Parts are in the
[parts list](parts-list.md); every pin is in [wiring](wiring.md).

## 1. Set up the firmware tools

1. Install [VS Code](https://code.visualstudio.com/) and the
   [PlatformIO extension](https://platformio.org/install/ide?install=vscode).
2. Clone this repo and open the folder in VS Code. PlatformIO downloads the
   ESP32 toolchain and the libraries (TFT_eSPI, TinyGPSPlus) on first build.
3. Run the unit tests on the computer: `pio test -e native`. They should
   all pass.

## 2. Flash the CYD (no wiring yet)

1. Format the MicroSD card **FAT32** and put it in the CYD.
2. Plug the CYD into the computer by USB.
3. Upload: the **→ Upload** button in the PlatformIO toolbar, or
   `pio run -e esp32dev -t upload`. If it sticks at `Connecting....`, hold
   the CYD's **BOOT** button until writing starts.
4. Open the serial monitor (115200 baud) in a terminal:
   `pio device monitor`. You should see:

   ```
   # Recording all CAN frames to SD /can_0001.log
   # CAN listen-only 500k. Frames go to the SD card only
   # 0 past rides on the card
   (0.9) note boot reset_reason=1 can=running sd=ok
   ```

5. Tap the screen: it should cycle Dashboard → Trip → … → CAN pages.
   Double-tap returns to the dashboard.

### Touch calibration

The touch-to-screen mapping is in `lib/dash_logic/src/touch_map.h`,
measured on this build's CYD. If taps land in the wrong place on yours:

1. Temporarily add `Serial.printf("raw %d %d\n", touchRawX, touchRawY);`
   where taps are handled in `src/main.cpp`.
2. Tap the top-left, top-right, bottom-right and bottom-left corners.
3. Put the readings into `TOUCH_RAW_LEFT/RIGHT/TOP/BOTTOM` and update the
   test in `test/test_touch_map`.

## 3. Wire the transceiver and GPS (bench)

1. **Transceiver to CN1:** red → 3V3, yellow → CRX, blue → CTX, black → GND
   ([table](wiring.md#3-cyd-cn1--can-transceiver)). Termination jumper
   **off**.
   - Recommended: tie **CTX to 3.3 V** instead of the blue wire, for a
     guaranteed read-only tap ([why](wiring.md#make-the-tap-truly-read-only)).
2. **GPS:** VCC → CN1 red (3.3 V), GND → P3 GND, TX → P3 IO35, RX not
   connected ([table](wiring.md#4-gps-u-blox-neo-m8n)).
3. Power up over USB and watch the serial monitor. The GPS line
   `# GPS chars=… sats=… fix=…` should show **chars** rising (wiring OK),
   then satellites and `fix=1` near a window or outdoors (2–10 minutes
   the first time, seconds after that).

## 4. Find and check the bike wires

Key off, seat off, at the diagnostic connector / offroad dongle under the
seat. Identify CAN-H, CAN-L, ground and switched 12 V with the meter
([how](wiring.md#finding-the-wires-with-a-meter)). On this bike: CAN-H
blue/black, CAN-L blue/white, ground brown, 12 V tan.

## 5. Build the bike pigtail

1. Splice into the dongle's four wires. **Stagger the joints** an inch
   apart, one piece of heat-shrink per joint, slid on before soldering.
2. **Heat-shrink carefully.** Low heat, one joint at a time, shield the
   neighbours. On this build the heat melted CAN-H into ground inside the
   jacket and shorted the whole bus
   ([details](troubleshooting.md#a-melted-wire-shorted-the-bus)).
3. Tan → fuse → converter +; brown → converter − and the ground conductor
   to the transceiver; blue/black and blue/white → the twisted pair.
4. **Test before plugging into the bike**
   ([checks](wiring.md#checks-before-connecting-to-the-bike)): nothing
   shorted to ground, then ~60 Ω across CAN-H/CAN-L once on the bike.

## 6. Power from the bike

1. Cut the USB-A cable, find +5 V and ground with the meter, and wire them
   to the CYD's **VIN** and **GND** ([table](wiring.md#2-power)).
2. With the key on, check **~5 V at VIN** and **~3.3 V at the transceiver's
   3V3 pin**.

## 7. First key-on

1. Key on. The dash boots; the ECU starts sending about **15 seconds** after
   key-on, so `--` until then is normal.
2. Check the CAN page header: **RUN** with a frame rate (several hundred per
   second), and the footer **REC can_NNNN.log** with KB climbing and
   drop/err at 0.
3. Start the engine: RPM, gear (N in green) and coolant go live; idle shows
   one cyan bar on the tach.
4. If the time spot on the dash shows **CAN FAULT**, the CAN wiring is bad
   (no frames, many errors). See [troubleshooting](troubleshooting.md).

## 8. Mounting

- Case: [`hardware/case/cyd-case.stl`](../hardware/case/README.md), printed in
  PETG or ASA. Leave the SD slot and USB port reachable.
- GPS antenna up, under plastic, away from metal.
- Strain relief on every cable where it enters the case and at every splice.
- In rain: a freezer bag over the case works; the touchscreen works
  through it.

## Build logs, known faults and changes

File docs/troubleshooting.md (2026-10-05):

# Troubleshooting

Problems hit while building this, how each was tracked down, and the fix.
Start with the [quick checks](#quick-checks).

## Quick checks

| Symptom | Look at |
|---|---|
| Dash shows `--` for everything right after key-on | Normal for ~15 s: the ECU starts sending after the ABS unit |
| **CAN FAULT** in red where the time goes | [CAN fault](#can-fault-on-the-dash) |
| No CAN frames, both CAN lines ~0 V | [A melted wire shorted the bus](#a-melted-wire-shorted-the-bus) |
| Screen frozen, taps do nothing (on the bike only) | [The dash froze on VIN power](#the-dash-froze-on-vin-power) |
| `No SD card: not recording` | Card not fully clicked in, or formatted exFAT (needs FAT32, 32 GB or less) |
| GPS `chars=0` | GPS TX not on IO35, or no power to the GPS |
| GPS `chars` rising but `sats=0` | It can't see the sky. Outdoors, antenna up; first fix can take 10 minutes |
| Upload stuck at `Connecting....` | Hold the CYD's BOOT button until writing starts |
| Taps land in the wrong place | Redo the [touch calibration](build-guide.md#touch-calibration) |

## A melted wire shorted the bus

**Symptom:** the dash got no CAN frames at all. With the key on, CAN-H and
CAN-L both read about **0.07 V** to ground, even back-probed at the dongle
with the dash unplugged. A healthy bus sits around 2.5 V.

**How it was found:** with the key off, CAN-H measured **~0 Ω to ground**.
Splitting the wiring in half each time: the short stayed with the dash
disconnected, stayed with the quick disconnect cut off, and turned out to be
in the dongle-side splices. Heat from shrinking the tubing had melted the
insulation between CAN-H and the ground wire inside the jacket.

**Fix:** cut back past the damage, insulate each wire separately,
re-splice with staggered joints, and use low heat with the neighbouring
wires shielded. Re-test: CAN-H and CAN-L to ground open, ~60 Ω between
them once on the bike, ~2.5 V with the key on.

**Note:** a shorted bus also stops the bike's own modules talking to each
other. After a fix, if the ABS behaves oddly, have its fault codes cleared.

## The dash froze on VIN power

**Symptom:** on the bike, the screen sat on the dashboard and ignored taps.
On the computer (USB power) everything worked.

**What the logs showed:** the GPS sends ~8 sentences a second, but only one
every 1–2 seconds reached the log, some garbled. The main loop was running
about once a second instead of tens of thousands of times.

**Suspected cause:** it started exactly when power moved from the USB port
to the VIN pin. Without USB, the CYD's USB-serial chip is unpowered and can
hold the ESP32's serial receive pin (GPIO 3) low, which looks like an endless
stream of broken characters, each one an interrupt.

**Fix (in the firmware):** the serial receive pin is disconnected
internally; the dash never reads from serial. Output and flashing still
work.

**Status: fixed (2026-10-05).** With this firmware change and the
[bus short](#a-melted-wire-shorted-the-bus) repaired, the dash runs on the
bike with live data and responsive touch. Both went in together, so which
one cured the freeze isn't certain. If it ever recurs, the `loop` notes in
the log (every 10 s) show which part of the loop is slow, or whether all of
it is (something outside the loop stealing time).

## CAN fault on the dash

If the CAN controller sees a flood of bus errors with few or no real frames
(transceiver unpowered, CAN-H/CAN-L swapped, no ground), the ESP32's driver
handles each error in an interrupt, which can starve everything else. The
firmware's guard (`lib/dash_logic/src/can_guard.h`) switches CAN off for 10
seconds when errors outnumber frames, then tries again. Meanwhile the dash
stays usable and shows **CAN FAULT**. The log gets `note CAN error flood …`
lines.

**Check:** transceiver 3V3 ~3.3 V, transceiver GND to battery − ~0 Ω,
CAN-H 2.5–3.5 V and CAN-L 1.5–2.5 V with the key on, yellow/blue on
CRX/CTX.

## Lost CAN frames (fixed)

**Symptom:** logs held ~350 frames/s, and rolling counters inside messages
skipped (25–50% of frames lost).

**Cause:** early firmware echoed every changed frame to the USB serial port.
At 115200 baud that couldn't keep up, and writes blocked the loop about
every 10 ms (an earlier "is there room?" check didn't help: the serial
library reports free space that doesn't account for its own overhead).

**Fix:** frames go to the SD card only; serial carries only status lines.

## Termination

The bike's bus already has both 120 Ω terminators: **~60 Ω** across CAN-H
and CAN-L with the key off. Keep the transceiver's termination jumper off.
If you measure ~120 Ω (one terminator missing), fitting the jumper restores
it; ~40 Ω means three, so take one off.

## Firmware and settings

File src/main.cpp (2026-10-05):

#include <Arduino.h>
#include <TFT_eSPI.h>
#include <esp_rom_gpio.h>
#include <esp_timer.h>
#include <soc/gpio_pins.h>
#include <soc/gpio_sig_map.h>
#include <sys/time.h>
#include "can_bus.h"
#include "candump_format.h"
#include "can_page.h"
#include "can_tracker.h"
#include "chart_page.h"
#include "dash_ui.h"
#include "gps.h"
#include "history_header.h"
#include "ktm_decode.h"
#include "loop_profiler.h"
#include "press_detector.h"
#include "reset_prompt.h"
#include "ride_history.h"
#include "ride_store.h"
#include "ride_clock.h"
#include "sd_log.h"
#include "tap_sequencer.h"
#include "touch.h"
#include "touch_map.h"
#include "trip_page.h"
#include "trip_stats.h"
#include "zones_page.h"

// 1 or 3 depending on which way the board is mounted (USB port left/right)
static const int SCREEN_ROTATION = 1;

static const unsigned long DASH_FRAME_MS = 40;
static const unsigned long CAN_PAGE_FRAME_MS = 250;
static const unsigned long STATS_PAGE_FRAME_MS = 500;
static const unsigned long GPS_STATUS_MS = 5000;
static const unsigned long TRIP_TICK_MS = 100;
static const unsigned long CHART_SAMPLE_MS = 2000;
static const unsigned long CLOCK_SYNC_MS = 60000;
// Turning the key off loses at most this much of a ride's history
static const unsigned long RIDE_SAVE_MS = 30000;
// How often the loop timing breakdown goes into the log
static const unsigned long PROFILE_REPORT_MS = 10000;

TFT_eSPI tft = TFT_eSPI();
DashUI dash(tft);
CanTracker canTracker;
CanPage canPage(tft, canTracker);
TripPage tripPage(tft);
ChartPage chartPage(tft);
ZonesPage zonesPage(tft);
PressDetector press;
LoopProfiler prof;
TapSequencer taps;
ResetPrompt resetPrompt;
Telemetry telemetry;
KtmState ktm;
GpsView gpsView;

// This ride, collected all the time whatever page is showing, and a saved
// past ride loaded for the history pages' < > buttons
RideRecord live, past;
RideBrowser rides;

// Fixed pages first, then the CAN ID list, CanPage::ROWS IDs per page
enum Page { PAGE_DASH, PAGE_TRIP, PAGE_ELEVATION, PAGE_SPEED, PAGE_ZONES, PAGE_COOLANT, FIRST_CAN_PAGE };

static int currentPage = PAGE_DASH;
static bool clockSet = false;  // set once GPS time arrives (syncClock)
static unsigned long lastFrameMs = 0;

static int canPageCount() {
    int n = canTracker.size();
    return n <= CanPage::ROWS ? 1 : (n + CanPage::ROWS - 1) / CanPage::ROWS;
}

static bool isStatsPage(int page) { return page >= PAGE_TRIP && page < FIRST_CAN_PAGE; }

// The ride the history pages are showing
static const RideRecord& shownRide() { return rides.viewingLive() ? live : past; }

// "THIS RIDE", or "#12 Sat Oct 3" for a saved one
static void rideLabel(char* out, size_t cap) {
    if (rides.viewingLive()) {
        snprintf(out, cap, "THIS RIDE");
        return;
    }
    char date[16] = "";
    if (past.startUtc) formatDate(date, sizeof(date), past.startUtc);
    snprintf(out, cap, "#%d %s", past.number, date);
}

static void showPage(int page) {
    currentPage = page;
    const RideRecord& r = shownRide();
    char label[24];
    rideLabel(label, sizeof(label));
    bool older = rides.hasOlder(), newer = rides.hasNewer();

    switch (page) {
    case PAGE_DASH: dash.begin(); break;
    case PAGE_TRIP: tripPage.begin(label, older, newer); break;
    case PAGE_ZONES: zonesPage.begin(label, older, newer); break;
    case PAGE_ELEVATION:
        chartPage.begin(r.elevation, {"ELEVATION", "ft", TFT_CYAN, 100, false}, CHART_SAMPLE_MS,
                        label, older, newer);
        break;
    case PAGE_SPEED: {
        ChartStyle style{"SPEED", "mph", TFT_WHITE, 20, true};
        style.overlay = &r.gpsSpeed;
        style.overlayColor = TFT_DARKGREEN;
        style.overlayLabel = "GPS";
        chartPage.begin(r.speed, style, CHART_SAMPLE_MS, label, older, newer);
        break;
    }
    case PAGE_COOLANT:
        chartPage.begin(r.coolant, {"COOLANT", "F", TFT_CYAN, 40, false}, CHART_SAMPLE_MS,
                        label, older, newer);
        break;
    default: {
        int canIndex = page - FIRST_CAN_PAGE;
        canPage.begin(canIndex * CanPage::ROWS, canIndex + 1, canPageCount());
    }
    }
    lastFrameMs = 0;  // draw immediately
}

static void nextPage() {
    showPage((currentPage + 1) % (FIRST_CAN_PAGE + canPageCount()));
}

// ---- Event markers: long press on the dash or CAN pages ----
static const unsigned long MARK_BANNER_MS = 1500;
static uint16_t markCount = 0;
static unsigned long markBannerUntilMs = 0;

static void dropMarker(unsigned long nowMs) {
    markCount++;
    char line[CANDUMP_LINE_MAX];
    int n = formatMarkerLine(line, sizeof(line), esp_timer_get_time(), markCount);
    sdLogWrite(line, n);
    Serial.write((const uint8_t*)line, n);  // rare, so a brief block is harmless

    tft.fillRect(90, 96, 140, 48, TFT_YELLOW);
    tft.setTextColor(TFT_BLACK, TFT_YELLOW);
    tft.setTextDatum(MC_DATUM);
    tft.drawString("MARK " + String(markCount), 160, 120, 4);
    markBannerUntilMs = nowMs + MARK_BANNER_MS;
}

// ---- Reset: long press on a trip/chart page, then tap to confirm ----
static bool promptShown = false;

static void showResetPrompt(unsigned long nowMs) {
    resetPrompt.open(nowMs);
    promptShown = true;
    tft.fillRoundRect(50, 80, 220, 80, 8, TFT_RED);
    tft.setTextColor(TFT_WHITE, TFT_RED);
    tft.setTextDatum(MC_DATUM);
    tft.drawString("TAP TO CLEAR", 160, 108, 4);
    tft.drawString("wait to cancel", 160, 140, 2);
}

static void resetCurrentPage() {
    switch (currentPage) {
    case PAGE_TRIP: live.trip = TripStats(); break;
    case PAGE_ZONES: live.trip.clearZones(); break;
    case PAGE_ELEVATION: live.elevation = Series(); break;
    case PAGE_SPEED: live.speed = Series(); live.gpsSpeed = Series(); break;
    case PAGE_COOLANT: live.coolant = Series(); break;
    }
}

// ---- Ride history: < older, > newer on the trip/chart/zones pages ----
static void stepRide(bool toOlder) {
    bool moved = toOlder ? rides.older() : rides.newer();
    if (!moved) return;
    // A file that can't be read (e.g. from older firmware) is skipped
    while (!rides.viewingLive() && !rideLoad(rides.viewing(), past)) {
        if (!(toOlder ? rides.older() : rides.newer())) {
            rides.showLive();
            break;
        }
    }
    showPage(currentPage);
}

static void saveRide(unsigned long nowMs) {
    static unsigned long lastSaveMs = 0;
    if (nowMs - lastSaveMs < RIDE_SAVE_MS) return;
    lastSaveMs = nowMs;
    if (!worthSaving(live.trip) || sdLogNumber() < 0) return;
    live.number = sdLogNumber();
    if (live.startUtc == 0 && clockSet) live.startUtc = time(nullptr) - live.trip.elapsedMs() / 1000;
    if (!rideSave(live)) Serial.println("# Could not save ride history");
}

// ---- Clock: set from GPS time; also gives SD log files real dates ----

static void syncClock(unsigned long nowMs) {
    static unsigned long lastSyncMs = 0;
    if (clockSet && nowMs - lastSyncMs < CLOCK_SYNC_MS) return;
    time_t utc;
    if (!gpsUtcTime(utc)) return;
    struct timeval tv = {utc, 0};
    settimeofday(&tv, nullptr);
    clockSet = true;
    lastSyncMs = nowMs;
}

// Engine values from the bike; "--" on the dash when their frames stop
static void updateTelemetry(Telemetry& t, const KtmState& k, unsigned long nowMs) {
    t.rpmLive = ktmRpmLive(k, nowMs);
    t.rpm = t.rpmLive ? k.rpm : 0;
    t.gear = ktmGearLive(k, nowMs) ? k.gear : -1;
    t.coolantLive = ktmCoolantLive(k, nowMs);
    t.coolantF = k.coolantF;
    t.speedLive = ktmSpeedLive(k, nowMs);
    t.speedMph = k.speedMph;

    t.canFault = canStatus().faulted;
    t.timeValid = clockSet;
    t.utc = time(nullptr);

    gpsUpdateView(gpsView, gpsReading());
    t.gpsFix = gpsView.fix;
    t.satellites = gpsView.satellites;
    t.headingDeg = gpsView.headingDeg;
    t.elevationFt = gpsView.elevationFt;
}

static void collectStats(const Telemetry& t, uint32_t dtMs) {
    TripSample s;
    s.speedLive = t.speedLive;
    s.speedMph = t.speedMph;
    s.rpmLive = t.rpmLive;
    s.rpm = t.rpm;
    s.coolantLive = t.coolantLive;
    s.coolantF = t.coolantF;
    s.elevationValid = t.gpsFix;
    s.elevationFt = t.elevationFt;
    live.trip.update(dtMs, s);
}

static void sampleCharts(const Telemetry& t) {
    live.elevation.add(t.gpsFix ? t.elevationFt : CHART_NO_DATA);
    live.speed.add(t.speedLive ? t.speedMph : CHART_NO_DATA);
    live.gpsSpeed.add(t.gpsFix ? gpsView.speedMph : CHART_NO_DATA);
    live.coolant.add(t.coolantLive ? t.coolantF : CHART_NO_DATA);
}

void setup() {
    Serial.setTxBufferSize(1024);  // only status lines and markers now
    // Transmit only. Powered through VIN with no USB cable, the CYD's USB-serial
    // chip is unpowered and can hold the ESP32's receive pin low, which looks
    // like an endless stream of broken characters, each one an interrupt.
    // Nothing reads Serial, so its receive pin (GPIO 3) isn't connected at all.
    // Flashing doesn't depend on this; the ROM bootloader handles it.
    Serial.begin(115200, SERIAL_8N1, -1, 1);
    // UART0's receive input is also wired to GPIO 3 by default inside the
    // chip; feed it a constant idle-high instead and leave the pin unused.
    pinMode(3, INPUT_PULLUP);
    esp_rom_gpio_connect_in_signal(GPIO_MATRIX_CONST_ONE_INPUT, U0RXD_IN_IDX, false);
    setenv("TZ", MOUNTAIN_TZ, 1);
    tzset();

    tft.init();
    tft.invertDisplay(true); // this CYD panel needs inversion for correct colours
    tft.setRotation(SCREEN_ROTATION);
    touchBegin();

    if (sdLogBegin()) Serial.printf("# Recording all CAN frames to SD %s\n", sdLogStatus().fileName);
    else Serial.println("# No SD card: not recording");
    if (!canBegin()) Serial.println("# TWAI failed to start");
    gpsBegin();

    static int saved[RideBrowser::CAPACITY];
    int n = rideList(saved, RideBrowser::CAPACITY);
    rides.setRides(saved, n, sdLogNumber());
    Serial.printf("# %d past rides on the card\n", n);

    char note[96];
    snprintf(note, sizeof(note), "boot reset_reason=%d can=%s sd=%s", (int)esp_reset_reason(),
             canStatus().running ? "running" : "NOT RUNNING", sdLogNumber() >= 0 ? "ok" : "none");
    sdLogNote(note);

    showPage(PAGE_DASH);
}

void loop() {
    unsigned long now = millis();
    prof.startPass(micros());
    static unsigned long lastProfileMs = 0;
    if (now - lastProfileMs >= PROFILE_REPORT_MS) {
        lastProfileMs = now;
        char report[200], note[240];
        prof.report(report, sizeof(report));
        SdLogStatus sd = sdLogStatus();
        snprintf(note, sizeof(note), "%s sd_kb=%lu sd_dropped=%lu sd_errors=%lu", report,
                 (unsigned long)(sd.bytesWritten / 1024), (unsigned long)sd.droppedLines,
                 (unsigned long)sd.writeErrors);
        sdLogNote(note);
    }

    // Keep the CAN queue drained every pass, whatever page is showing
    canPoll(canTracker, ktm, now);
    canTracker.updateRates(now);
    prof.mark(PROF_CAN, micros());
    gpsPoll();
    syncClock(now);
    prof.mark(PROF_GPS, micros());

    // Trip stats and charts keep collecting on every page
    static unsigned long lastTripMs = now, lastChartMs = now;
    if (now - lastTripMs >= TRIP_TICK_MS) {
        updateTelemetry(telemetry, ktm, now);
        collectStats(telemetry, now - lastTripMs);
        lastTripMs = now;
    }
    if (now - lastChartMs >= CHART_SAMPLE_MS) {
        sampleCharts(telemetry);
        lastChartMs += CHART_SAMPLE_MS;
    }
    saveRide(now);
    prof.mark(PROF_STATS, micros());

    // GPS status for bench checks over USB, every few seconds
    static unsigned long lastGpsStatusMs = 0;
    if (now - lastGpsStatusMs >= GPS_STATUS_MS) {
        lastGpsStatusMs = now;
        char clock[16] = "--:--", date[16] = "";
        if (clockSet) {
            formatClock(clock, sizeof(clock), time(nullptr));
            formatDate(date, sizeof(date), time(nullptr));
        }
        Serial.printf("# GPS chars=%lu sats=%d fix=%d time=%s %s\n", (unsigned long)gpsCharsReceived(),
                      gpsView.satellites, gpsView.fix, date, clock);
    }
    prof.mark(PROF_SERIAL, micros());

    // Where the screen is being touched, kept from while the finger was down
    static int touchRawX = 0, touchRawY = 0;
    touchReadRaw(touchRawX, touchRawY);

    PressEvent ev = press.update(touchIsPressed(), now);
    prof.mark(PROF_TOUCH, micros());
    if (ev == PRESS_TAP) {
        int x, y;
        touchToScreen(touchRawX, touchRawY, x, y);
        taps.tap(now, x, y);
    }
    if (ev == PRESS_LONG) {
        // Saved rides can't be reset; long press does nothing there
        if (!isStatsPage(currentPage)) dropMarker(now);
        else if (rides.viewingLive()) showResetPrompt(now);
    }

    TapResult tap = taps.poll(now);
    if (tap.kind == TAP_DOUBLE) {
        // Double tap anywhere: back to the dashboard and this ride
        resetPrompt.confirm(0);  // closes it without resetting
        promptShown = false;
        rides.showLive();
        showPage(PAGE_DASH);
    } else if (tap.kind == TAP_SINGLE) {
        if (resetPrompt.isOpen(now)) {
            if (resetPrompt.confirm(now)) resetCurrentPage();
            promptShown = false;
            showPage(currentPage);
        } else if (isStatsPage(currentPage) && tapHitsOlder(tap.x, tap.y)) {
            stepRide(true);
        } else if (isStatsPage(currentPage) && tapHitsNewer(tap.x, tap.y)) {
            stepRide(false);
        } else {
            nextPage();
        }
    }

    // Hold the marker banner, then redraw the page underneath it
    if (markBannerUntilMs != 0) {
        if ((long)(now - markBannerUntilMs) < 0) return;
        markBannerUntilMs = 0;
        showPage(currentPage);
    }
    // Hold the reset prompt; if it timed out, put the page back
    if (promptShown) {
        if (resetPrompt.isOpen(now)) return;
        promptShown = false;
        showPage(currentPage);
    }

    unsigned long frameMs = currentPage == PAGE_DASH ? DASH_FRAME_MS
                          : isStatsPage(currentPage)  ? STATS_PAGE_FRAME_MS
                                                      : CAN_PAGE_FRAME_MS;
    if (lastFrameMs != 0 && now - lastFrameMs < frameMs) return;
    lastFrameMs = now;

    switch (currentPage) {
    case PAGE_DASH: dash.update(telemetry, now); break;
    case PAGE_TRIP: tripPage.update(shownRide().trip); break;
    case PAGE_ZONES: zonesPage.update(shownRide().trip); break;
    case PAGE_ELEVATION:
    case PAGE_SPEED:
    case PAGE_COOLANT: chartPage.update(); break;
    default: canPage.update(canStatus(), sdLogStatus(), now);
    }
    prof.mark(PROF_UI, micros());
}

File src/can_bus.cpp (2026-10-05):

#include "can_bus.h"

#include <Arduino.h>
#include <driver/twai.h>
#include <esp_timer.h>
#include "can_guard.h"
#include "candump_format.h"
#include "sd_log.h"

// CYD CN1 connector -> SN65HVD230
static const gpio_num_t CAN_TX_PIN = GPIO_NUM_22;
static const gpio_num_t CAN_RX_PIN = GPIO_NUM_27;

// Deep enough to ride out a full-screen redraw at a busy bus's frame rate
static const int RX_QUEUE_LEN = 256;

// Frames handled per canPoll() call, so touch and the display always get a
// turn even if frames arrive faster than one pass can drain them
static const int MAX_FRAMES_PER_POLL = 64;

// How often the error guard looks at the controller, and how often a
// health line goes into the SD log
static const unsigned long GUARD_CHECK_MS = 250;
static const unsigned long HEALTH_LOG_MS = 10000;

static bool installed = false;
static bool running = false;
static CanGuard guard;
static uint32_t framesTotal = 0;
static uint32_t errorsTotal = 0;  // never goes backwards, even if the driver's does

bool canBegin() {
    twai_general_config_t g = TWAI_GENERAL_CONFIG_DEFAULT(CAN_TX_PIN, CAN_RX_PIN, TWAI_MODE_LISTEN_ONLY);
    g.rx_queue_len = RX_QUEUE_LEN;
    twai_timing_config_t t = TWAI_TIMING_CONFIG_500KBITS();
    twai_filter_config_t f = TWAI_FILTER_CONFIG_ACCEPT_ALL();

    if (twai_driver_install(&g, &t, &f) != ESP_OK) return false;
    installed = true;
    if (twai_start() != ESP_OK) return false;

    running = true;
    Serial.println("# CAN listen-only 500k. Frames go to the SD card only");
    return true;
}

static void updateErrorTotal() {
    static uint32_t lastDriverCount = 0;
    twai_status_info_t info;
    if (!running || twai_get_status_info(&info) != ESP_OK) return;
    uint32_t count = info.bus_error_count;
    errorsTotal += count >= lastDriverCount ? count - lastDriverCount : count;
    lastDriverCount = count;
}

static void guardCheck(unsigned long nowMs) {
    static unsigned long lastCheckMs = 0, lastHealthMs = 0;
    if (!installed || nowMs - lastCheckMs < GUARD_CHECK_MS) return;
    lastCheckMs = nowMs;

    updateErrorTotal();
    char text[80];
    switch (guard.check(nowMs, framesTotal, errorsTotal)) {
    case GUARD_STOP:
        twai_stop();
        running = false;
        snprintf(text, sizeof(text), "CAN error flood (frames=%lu errors=%lu): CAN off for %lu s",
                 (unsigned long)framesTotal, (unsigned long)errorsTotal, CAN_GUARD_PAUSE_MS / 1000);
        sdLogNote(text);
        break;
    case GUARD_RESTART:
        running = twai_start() == ESP_OK;
        sdLogNote(running ? "CAN restarted" : "CAN restart failed");
        break;
    case GUARD_NONE:
        break;
    }

    if (nowMs - lastHealthMs >= HEALTH_LOG_MS) {
        lastHealthMs = nowMs;
        snprintf(text, sizeof(text), "can frames=%lu errors=%lu%s", (unsigned long)framesTotal,
                 (unsigned long)errorsTotal, guard.faulted() ? " FAULT" : "");
        sdLogNote(text);
    }
}

void canPoll(CanTracker& tracker, KtmState& ktm, unsigned long nowMs) {
    guardCheck(nowMs);
    if (!running) return;

    twai_message_t m;
    for (int i = 0; i < MAX_FRAMES_PER_POLL && twai_receive(&m, 0) == ESP_OK; i++) {
        if (m.rtr) continue;
        framesTotal++;

        // 64-bit microseconds since boot; micros() would wrap after 71 min
        char line[CANDUMP_LINE_MAX];
        int n = formatCandumpLine(line, sizeof(line), esp_timer_get_time(),
                                  m.identifier, m.extd, m.data_length_code, m.data);
        sdLogWrite(line, n);  // every frame goes to the card
        ktmDecodeFrame(ktm, nowMs, m.identifier, m.extd, m.data_length_code, m.data);

        tracker.record(m.identifier, m.extd, m.data_length_code, m.data, nowMs);
    }
}

CanBusStatus canStatus() {
    CanBusStatus s;
    s.running = running;
    s.faulted = guard.faulted();
    s.busErrors = errorsTotal;
    if (!running) {
        s.state = s.faulted ? "CAN FAULT" : "OFF";
        return s;
    }

    twai_status_info_t info;
    if (twai_get_status_info(&info) != ESP_OK) return s;
    s.rxMissed = info.rx_missed_count;
    switch (info.state) {
        case TWAI_STATE_RUNNING:    s.state = s.faulted ? "CHECKING" : "RUN"; break;
        case TWAI_STATE_BUS_OFF:    s.state = "BUS OFF"; break;
        case TWAI_STATE_RECOVERING: s.state = "RECOVER"; break;
        default:                    s.state = "STOPPED"; break;
    }
    return s;
}

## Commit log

2026-10-05 Add KTM 690 dash firmware, docs and CAN captures
    ESP32 CYD dashboard and logger for a 2020 KTM 690 Enduro R: read-only CAN
    decoding (RPM, gear, coolant, wheel speed), NEO-M8N GPS with local time,
    trip stats, charts, ride history, and SD logging with rotation.
    Docs cover the parts list, every wire, the build, using the dash, the CAN
    signals found so far, the log format, firmware layout and troubleshooting.
    Captures are the bike's CAN logs with GPS positions removed.
2026-10-05 Mark the VIN-power freeze as fixed on the bike
    The dash now runs on the bike with live data and responsive touch, after
    both the serial-receive change and the bus short repair.
2026-10-08 Add the 3D-printed case for the CYD dash
    One-plate STL with the dash front and back, the GPS/electronics box and
    four posts, plus print notes, linked from the build guide and parts list.
    [cyd-case.stl]
2026-10-08 Add compatibility notes for other model years and connectors
    Which 690-platform bikes should work, the 2021 Euro 5 diagnostic connector
    change, and that the offroad dongle isn't required.
2026-10-20 Bring up the Waveshare 5" board: display, touch, SD and CAN
    New waveshare5 build target with its own code in src/w5/: LovyanGFX setup
    for the 800x480 RGB panel (Waveshare's timings), CH422G expander and GT911
    touch drivers, and a bring-up screen with live SD and CAN status.
    CAN and SD logging are shared with the CYD build, with board-specific
    pins. On the 5" the SD card runs in SD mode (1-bit) because its SPI chip
    select is on the expander, which the SPI library can't drive.
2026-10-21 Read the GPS through an SC16IS750 bridge on the 5" board
    The 5" board has no free UART pins, so the NEO-M8N connects through an
    SC16IS750 I2C-to-UART bridge on the screw terminal's I2C (address 0x4D).
    gps.cpp reads from the bridge on that board and from UART2 on the CYD.
    The bring-up screen now shows GPS status and scans the I2C bus at boot.
